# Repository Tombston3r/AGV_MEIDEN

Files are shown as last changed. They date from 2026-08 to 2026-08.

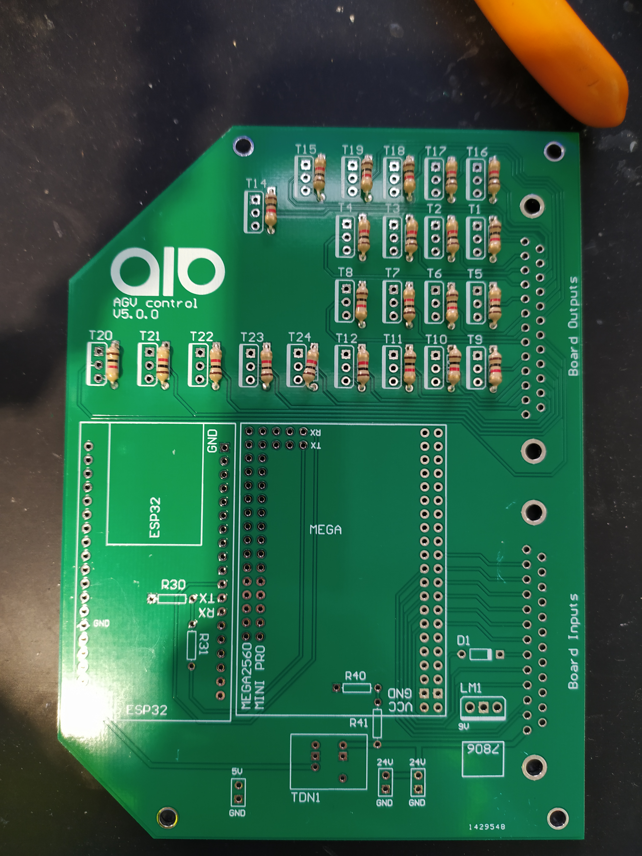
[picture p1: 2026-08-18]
Comm distance/architectures/A3_Wifi/hardware/photos/assemblagecartewifi_1.jpg

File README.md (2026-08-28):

# AGV MEIDEN

Deux chantiers sur le même chariot filoguidé MEIDEN (carte d'origine
`AIO AGV Control V5.0.1`) :

Toutes les architectures suivent la **même chaîne** depuis le 2026-08-28 :

```
Boutons d'appel (optionnels) -> Poste Central -> Carte AGV Control -> AGV
                                API planning
                                appels
```

Les boutons sont **optionnels** : le planning seul fait rouler l'AGV. Les trois
architectures ne diffèrent plus que par la **liaison du poste vers l'AGV** :
[`docs/ARCHITECTURE_COMMUNE.md`](docs/ARCHITECTURE_COMMUNE.md).

| Dossier | Chantier | État |
|---|---|---|
| [`Comm distance/`](Comm%20distance/) | **Remplacement du système d'appel** : 4 architectures étudiées (cellulaire, hybride, LoRa, Wi-Fi), bancs d'essai, matériel KiCad | 470 tests verts, choix client non tranché |
| [`Timer/`](Timer/) | **Planning journalier** : missions déclenchées sur horloge, validation quotidienne par l'opérateur | moteur livré, 18 tests verts |

Chaque chantier porte son `README.md` **et** son `DEPLOY.md`, à quoi ça sert
d'un côté, comment le mettre en service et ce qu'on doit voir de l'autre. La
règle de rangement commune est dans
[`docs/ORGANISATION.md`](docs/ORGANISATION.md) : *tout ce qui sert à une chose
vit avec elle, documentation comprise.*

Toutes les interfaces web du dépôt suivent le **même thème** : fond blanc,
bleu outremer, logo AIO : [`docs/theme/`](docs/theme/), propagé par
`outils/theme.sh`.

Les deux partagent la même carte et le même cœur métier : le Timer produira
ses missions vers le séquenceur déjà écrit dans
[`Comm distance/architectures/A3_Wifi/`](Comm%20distance/architectures/A3_Wifi/).

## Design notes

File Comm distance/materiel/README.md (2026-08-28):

# Matériel : projets KiCad

**Une carte, un projet, un seul endroit.** Même quand deux architectures
partagent une carte, elle n'est pas dupliquée : trois copies divergentes de la
V6.0 ont déjà coexisté dans ce dépôt, et il a fallu comparer les schémas pour
savoir laquelle portait le travail réel. Un firmware dupliqué se compare par
`diff` ; deux schémas KiCad divergents, non.

| Projet | Sert à | Empreintes | État |
|---|---|---:|---|
| [`AIO_AGV_Control_V5.0.1/`](AIO_AGV_Control_V5.0.1/) | **A3** : Wi-Fi | 57 | carte d'origine, **en service sur le chariot** |
| [`AIO_AGV_Control_V6.0/`](AIO_AGV_Control_V6.0/) | **A2** et **A3** : LoRa | 59 | Gerbers exportés |

## Ce qui distingue la V6.0

Le diff des deux projets ne montre **aucun écart** hors la radio : mêmes
`Mega2560 Pro` et `ESP32-DEVKITC`, mêmes 23 `IRF520` et résistances de grille,
même `L7806CV`, même `TDN 5-2411WISM`, mêmes SUB-D 25.

S'y ajoutent un **`RFM95W-868S2` (U2)** et son **embase coaxiale (J3)**.

### Brochage relevé

| RFM95W | ESP32 |
|---|---|
| `NSS` | `IO5` |
| `SCK` | `IO18` |
| `MISO` | `IO19` |
| `MOSI` | `IO23` |
| `DIO0` | `IO26` |

⚠️ **`RESET` (pad 6) n'est pas connectée.** Aucun reset logiciel n'est possible :
un module figé ne se récupérera qu'en coupant l'alimentation de la carte.
**`IO27` est libre** et conviendrait, sans fonction de strapping au démarrage,
contrairement à `IO0`, `IO2`, `IO12` ou `IO15`.

⚠️ **`IO16` et `IO17` sont réservées** : elles portent la liaison série vers le
`Mega2560 Pro`, via un pont diviseur 2,2 k / 4,7 k dans le sens 5 V → 3,3 V.

## Points relevés sur la V5.0.1, valables pour les deux

- **Les trois UART matériels du MEGA sont inutilisables** : leurs broches de
  réception portent `Y13` (D19), `Y11` (D17) et `Y05` (D15). La liaison
  inter-microcontrôleurs est en `SoftwareSerial` sur D52/D53, à 38 400 bauds.
- **L'`IRF520` n'est pas un MOSFET logic-level** : seuil spécifié de 2 à 4 V,
  `Rds(on)` garanti à Vgs = 10 V. Attaqué en 5 V il conduit, mais hors des
  conditions du constructeur. L'`IRL520N` est la version logic-level **au même
  brochage**.
- **Les 21 entrées Y arrivent directement sur les broches de l'ATmega**, sans
  protection. Le client a vérifié que les niveaux le permettent.

Le relevé complet du câblage SUB-D vit dans
[`../architectures/A3_Wifi/docs/subd25_atmega.md`](../architectures/A3_Wifi/docs/subd25_atmega.md).

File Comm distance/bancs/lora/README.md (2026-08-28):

# Banc d'essai de la liaison LoRa

Ces essais servent à répondre à une seule question avant tout déploiement :
**la liaison passe-t-elle, et les deux extrémités se comprennent-elles ?**

Ce sont deux questions distinctes, et la seconde est la plus traître. Une radio
qui porte et des trames qui divergent d'un bit donne un banc parfait et une
panne en atelier. C'est pourquoi les deux côtés utilisent **la trame
applicative du projet**, pas un message d'essai.

```
bancs/lora/
├── esp32/      carte AGV ou poste ESP32 : PlatformIO / ESP-IDF
└── linux/      poste fixe Linux : Python 3
```

Les tests unitaires du transport LoRa, eux, restent dans
[`../../architectures/A2_LoRa/test/native/`](../../architectures/A2_LoRa/test/native/) :
ils n'ont besoin d'aucun matériel et tournent avec `make test`.

## Ce qui tourne sans matériel

```bash
cd linux && ./test_interop_trame.py
```

Compile le codec C++ du cœur métier, lui fait produire des vecteurs, et vérifie
que `agv_frame.py` encode **octet pour octet la même chose** : extension
d'horodatage comprise. C'est le contrôle qui garantit que les deux dossiers
d'essai parlent vraiment la même langue.

## Les quatre combinaisons

| Émetteur | Récepteur | Ce que ça éprouve |
|---|---|---|
| `esp32/ -e tx` | `esp32/ -e rx` | La radio et le pilote du projet, en boucle |
| `linux/test_tx.py` | `linux/test_rx.py` | Le pilote Python, en boucle |
| **`esp32/ -e tx`** | **`linux/test_rx.py`** | **L'interopérabilité réelle : AGV → poste** |
| **`linux/test_tx.py`** | **`esp32/ -e rx`** | **L'interopérabilité réelle : poste → AGV** |

Les deux dernières sont celles qui comptent. Les deux premières ne prouvent que
la cohérence d'une implémentation avec elle-même.

## Côté ESP32 : deux cartes possibles

```bash
cd esp32
pio run -e v6_tx    -t upload -t monitor    # carte V6.0, émission
pio run -e v6_rx    -t upload -t monitor    # carte V6.0, écoute
pio run -e tbeam_tx -t upload -t monitor    # LILYGO T-Beam, émission
pio run -e tbeam_rx -t upload -t monitor    # LILYGO T-Beam, écoute
```

Une **LILYGO T-Beam 868 MHz** porte le **même SX1276** que le `RFM95W` de la
carte V6.0 : le `RFM95W` n'est qu'un module HopeRF enveloppant cette puce. Le
pilote du projet fonctionne donc tel quel ; seul le brochage change, et il est
décrit dans `include/test_config.h`.

### Ce qu'elle apporte au banc

**Son écran affiche le relevé en direct.** C'est ce qui rend le relevé de portée
praticable : la carte tient dans une main, on marche le long du parcours et on
lit le niveau reçu, sans ordinateur au bout d'un câble USB.

```
Banc LoRa - ecoute

RSSI    -87 dBm
SNR      +9 dB
recues 42  rej 0
marge correcte
```

Sous −115 dBm, la dernière ligne passe à `!! MARGE FAIBLE`.

**Son bouton déclenche une émission à la demande.** Au relevé, on veut mesurer
*au point où l'on se trouve*, pas au rythme d'une boucle : l'environnement
`tbeam_tx` attend un appui avant chaque trame.

**Elle est sur batterie**, et affiche sa tension : un relevé qui s'arrête est
alors une liaison perdue ou une batterie vide, et on sait laquelle.

**Sa broche `RESET` est câblée**, contrairement à la V6.0 : un module figé s'y
récupère sans couper l'alimentation.

⚠️ **Sur T-Beam, la radio est alimentée par un gestionnaire AXP192**, pas
directement. Sans l'avoir activée, le SX1276 est hors tension et `RegVersion`
lit `0x00` : on cherche alors un défaut de câblage SPI qui n'existe pas. C'est
la cause n°1 des « la radio est morte » sur cette carte. `src/tbeam_power.cpp`
s'en charge et le dit à l'écran.

⚠️ **Le brochage change d'une révision à l'autre.** Le profil fourni est celui
de la **v1.1**, la plus répandue. Sur une v0.7 (sans AXP192) ou une v1.2
(AXP2101, registres différents), vérifier avant de flasher : le numéro est
sérigraphié près du connecteur USB.

Brochage par défaut : les broches **libres** relevées au projet KiCad de la
carte V5.0.1, dont l'`ESP32-DEVKITC` n'utilise que 4 broches sur 38 :

| RFM95W | ESP32 |
|---|---|
| SCK | `IO18` |
| MISO | `IO19` |
| MOSI | `IO23` |
| NSS | `IO5` |
| RESET | `IO14` |
| DIO0 | `IO26` |

⚠️ **Ne jamais utiliser `IO16` ni `IO17`** : elles portent la liaison série
vers le `Mega2560 Pro`. Un `static_assert` le rappelle dans `test_config.h`.

Ces essais compilent le **pilote du projet** (`Sx1276Radio`) et son
**budget de rapport cyclique** (`DutyCycleBudget`), pas une bibliothèque tierce.
Ils éprouvent donc le code qui partira en production.

## Côté Linux

```bash
cd linux
sudo apt install python3-spidev python3-libgpiod
./test_tx.py --count 10 --station 42
./test_rx.py --survey                  # relevé de portée : RSSI/SNR
```

⚠️ **Un `Unipi Gate G100` ne convient pas** : c'est un boîtier DIN fermé, sans
connecteur SPI ni GPIO. Ces scripts demandent une machine qui expose un bus
SPI : un modèle UniPi à base de Raspberry Pi, ou un adaptateur USB-SPI. C'est
la raison pour laquelle la nomenclature retient une carte ESP32 pour le poste
LoRa, et non une passerelle : voir `../../architectures/A2_LoRa/BOM.md`, « Pourquoi pas un Unipi
Gate pour ce poste ? ».

## Lire les résultats

**Le taux d'accusés** est la mesure utile. 100 % sur 20 trames à poste fixe ne
prouve rien ; c'est le relevé **le long du parcours**, chariot chargé, qui
compte.

**Le RSSI plancher** décide de la marge. Sous **−115 dBm**, les deux scripts
avertissent : un chariot chargé entre les deux antennes suffira à couper la
liaison. Un lien qui « passe tout juste » ne passe pas.

**Le budget de rapport cyclique** est appliqué des deux côtés, y compris sur
les accusés : un récepteur qui acquitte est un émetteur. À SF9, une trame de
9 octets occupe ~145 ms d'antenne, ce qui plafonne à **~248 émissions par
heure**, accusés compris. Les scripts refusent d'émettre au-delà et le disent.
Ce n'est pas un réglage : c'est l'EN 300 220 / ERC 70-03.

**`--sf 7` change tout** : ~41 ms au lieu de ~145, donc 3,5 fois plus
d'émissions possibles et une latence bien plus basse, au prix de la portée.
C'est l'arbitrage décrit dans [`../../architectures/A2_LoRa/docs/latence_lora.md`](../../architectures/A2_LoRa/docs/latence_lora.md),
et ces essais sont faits pour le trancher sur le terrain plutôt qu'au bureau.

## La T-Beam peut-elle servir de télécommande finale ?

**Comme prototype, oui et c'est même recommandé.** Elle permet d'éprouver tout
le comportement du bouton A3 (protocole, latence, accusé, budget légal) et de
le faire essayer par un opérateur pendant quelques semaines, **avant** d'engager
un circuit imprimé. C'est le meilleur moyen de dérisquer la carte définitive.

**En production, non.** La raison tient en une ligne :

| | Sommeil | Réserve | Autonomie |
|---|---:|---:|---:|
| T-Beam, sommeil soigné | 0,3 mA | 18650, 3 000 mAh | **~14 mois** |
| T-Beam, sommeil courant | 1,0 mA | 18650, 3 000 mAh | **~4 mois** |
| Bouton A3 (`STM32L071` + `ER14505`) | 0,002 mA | Li-SOCl₂, 2 600 mAh | **5 à 8 ans** |

L'écart n'est pas un défaut de réglage : un ESP32 avec son gestionnaire
d'alimentation, sa puce USB-série et son écran consomme au repos mille fois ce
que consomme un microcontrôleur de la famille L0. Il ne se rattrape pas.

Trois autres points, moins spectaculaires mais réels :

- **Ce n'est pas un bouton.** C'est une carte de développement avec un accu
  18650 qui dépasse. Il faudrait lui ajouter un boîtier IP65 et un poussoir Ø22
  câblé sur une entrée, soit l'essentiel de la nomenclature du bouton A3, sans
  en avoir l'autonomie.
- **Ce n'est pas du matériel industriel** : connecteur USB exposé, pas de
  vernis, qualité grand public, dans un atelier à poussière et vibrations.
- **Les révisions changent de brochage** et sortent du catalogue. Pour une
  installation prévue pour dix ans, c'est un risque d'approvisionnement.

En revanche, **rien ne s'oppose à ce qu'elle serve de poste fixe d'essai** dans
l'architecture A2 : sur secteur, la consommation n'a plus d'importance, et son
écran affiche l'état de la liaison.

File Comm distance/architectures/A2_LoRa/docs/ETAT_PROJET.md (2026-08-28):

# État du projet : architecture Wi-Fi (carte V5.0.1 conservée)

> **Document vivant.** Mis à jour à chaque modification du dossier.
>
> Dernière mise à jour : **2026-08-18**, poste fixe ramené à une passerelle
> Unipi Gate G100, ce qui lève le point ouvert §12.9.
>
> **Périmètre** : `architectures/A3_Wifi/`, projet autonome et zippable. La carte AIO
> AGV Control V5.0.1 est **conservée** ; ses **deux firmwares sont réécrits**.
> Index des architectures : [`../../README.md`](../../README.md).
> Spécification suivie : [`Planification_Architecture_WiFi_AGV.md`](Planification_Architecture_WiFi_AGV.md).

---

## 1. Ce qui est fait

### 1.1 Vue d'ensemble

| Indicateur | Valeur |
|---|---|
| Tests natifs C++ | **109 tests, 537 assertions, 0 échec** |
| Tests Python (poste UniPi) | **17 tests, 0 échec** (rejoués à la main, `pytest` absent du poste) |
| Compilation | `-std=c++17 -Wall -Wextra -Werror`, sans avertissement |
| Matériel nécessaire | **aucun** |
| Firmwares réécrits | ESP32 **et** ATmega2560 |

```bash
python3 tools/genconfig.py profiles/default.yaml \
        firmware/common/config/generated_profile.h
make test
```

### 1.2 Répartition des rôles : la décision structurante

Détail et justification : [`carte_v5_architecture.md`](carte_v5_architecture.md).

| Microcontrôleur | Porte | Ne porte pas |
|---|---|---|
| **ATmega2560** | séquenceur trois phases, file de 5 courses, décodage position 10 bits, repli de sécurité | rien de réseau |
| **ESP32** | client Wi-Fi STA, client MQTT, heartbeat, AP de maintenance, `/agvdump` | **jamais le bus MEIDEN** |

Motif : chaque maillon réseau (Wi-Fi, DHCP, handover, TLS, broker, poste) peut
tomber pour des raisons hors projet. Le séquenceur ne doit dépendre d'aucun.

### 1.3 Repli de sécurité : le mécanisme central

L'ESP32 émet un heartbeat toutes les 500 ms. Sans heartbeat pendant 2 s,
l'ATmega termine la course engagée **jusqu'au point d'arrêt suivant**, refuse
toute nouvelle course, et le signale (`safe_stop`).

Vérifié par 6 tests dédiés, dont :

- refus de toute course tant qu'aucun heartbeat n'a été reçu (état au boot) ;
- perte en pleine course → la course va au bout, la suivante n'est pas lancée ;
- **le retour du heartbeat ne relance rien tout seul** ;
- un heartbeat manqué isolément n'immobilise pas l'AGV.

### 1.4 Firmware ATmega2560 (réécrit)

| Élément | État |
|---|---|
| Séquenceur trois phases, 12 états, tous timeouts instrumentés | ✅ |
| File de 5 courses, priorité, purge | ✅ (RAM, planification §2.3) |
| Décodage position 10 bits `Y23`…`Y34` et vitesse `Y11`…`Y14` | ✅ |
| Pose des 22 lignes en **une seule section critique** (5 écritures de port) | ✅ testé |
| Masquage des ports mixtes PA/PB/PG (DDR et données) | ✅ testé |
| Étage de sortie **poussé** : la broche attaque une grille de MOSFET | ✅ testé |
| Table de câblage réelle CN61→CN64 | ✅ relevée |
| Idempotence : même séquence ré-acquittée sans ré-exécution | ✅ |
| Repli heartbeat | ✅ |
| **Mode découverte du brochage SUB-D** | ✅ (contrôle, plus relevé) |

### 1.5 Firmware ESP32 (réécrit)

| Élément | État |
|---|---|
| Client Wi-Fi **STA** (plus de point d'accès permanent) | ✅ |
| IP statique pour supprimer le délai DHCP au handover | ✅ |
| Client MQTT : `state` (retained, 1 s), `cmd`, `ack`, LWT sur `status` | ✅ |
| Heartbeat vers l'ATmega, **maintenu même sans Wi-Fi** | ✅ testé |
| Péremption des commandes (30 s), doublons, désordre | ✅ testé |
| AP de maintenance à la demande (ILS, 10 min) en **APSTA** | ✅ |
| `/agvdump` au format atelier | ✅ testé |

### 1.6 Liaison inter-MCU

Protocole documenté dans `link/link_protocol.h` : SOF distinct par sens,
CRC-16/CCITT, resynchronisation automatique, longueur invalide rejetée.
7 tests dédiés.

### 1.7 Poste fixe UniPi

| Élément | État |
|---|---|
| Décodeur ESP3 (TCM 515) en Python | ✅ |
| Déduplication des 3 sous-télégrammes PTM 210 | ✅ |
| Table d'appairage persistée + mode appairage | ✅ |
| Publication MQTT horodatée, séquence roulante | ✅ |
| Traçabilité des appuis (`poste/1/button/<id>`) | ✅ |
| Indicateur de fraîcheur de l'état | ✅ |
| Service systemd | ✅ |

### 1.8 Ce qui n'a **pas** pu être vérifié ici

- **Aucun des deux firmwares n'a été compilé pour sa cible** : ni PlatformIO,
  ni ESP-IDF, ni avr-gcc sur ce poste. Le cœur métier compile en natif avec
  `-Werror`, ce qui couvre la logique, pas les API ESP-IDF/Arduino.
- **`pytest` absent** : les 17 tests Python ont été rejoués par un harnais
  maison, pas par pytest.
- **Aucun essai matériel** : ni carte, ni banc, ni AGV, ni relevé réseau.
- **L'amplitude des lignes Y reste inconnue** (W1b), et la nomenclature KiCad
  confirme qu'**aucune protection n'est prévue** : la carte ne compte que quatre
  résistances hors étage de sortie, deux diviseurs de mesure. Les 21 lignes `Y`
  arrivent directement sur les broches du Mega. C'est la mesure la plus urgente.
- **La tension V_CC réelle de l'ATmega n'est pas mesurée** (W1e) : 6 V est le
  maximum absolu du datasheet.

---

## 2. Déploiement en conditions réelles

> 📖 **Procédure opérationnelle détaillée : [`../DEPLOY.md`](../DEPLOY.md)**,
> checklists, commandes, essais de recette et fiche à viser. Ce qui suit en est
> le résumé ; en cas d'écart, c'est `DEPLOY.md` qui fait foi.
>
> ⚠️ **Ordre non négociable.** Les étapes 0 à 2 conditionnent tout le reste.

### Étape 0 : Prérequis bloquants (planification §3)

| # | Tâche | Pourquoi bloquant |
|---|---|---|
| 0.1 | **Accord du service informatique** : VLAN OT, IP, pare-feu, 802.1X, notification de changement | Chemin critique du projet, délai hors de votre contrôle. À lancer le jour 1 |
| 0.2 | **Relevé de couverture Wi-Fi à hauteur d'antenne AGV**, trajet complet, en production | Un relevé fait à 1,50 m avec un portable ne vaut rien |
| 0.3 | Test de portée EnOcean bouton → poste, à chaque marqueur | Un bouton hors portée échoue **silencieusement** |
| 0.4a | ⚠️ **Mesurer l'amplitude d'une ligne Y** (`Y05`) et la tension V_CC de l'ATmega | Les Y arrivent directement sur des broches ; au-delà de V_CC + 0,5 V l'entrée est détruite. **Avant tout branchement** |
| 0.4c | Mesurer le tirage des entrées de l'automate | Décide entre collecteur ouvert et sortie poussée |
| 0.4b | Chronogramme X/Y, `t_setup`, PNP/NPN | Sans ça, les timings du profil sont des devinettes |
| 0.5 | Tentative de lecture des flash existantes (`esptool`, `avrdude`/ICSP) | Peut confirmer ou infirmer les hypothèses de câblage |
| 0.7 | **Décision de bande** : 2,4 GHz, ESP32-C5 bi-bande, ou bridge industriel | La saturation 2,4 GHz est le problème d'origine |

### Étape 1 : Poste de développement

```bash
pip install platformio
cd poste-unipi && pip install -e '.[dev,mqtt,enocean_serial]' && cd ..

python3 tools/genconfig.py profiles/default.yaml \
        firmware/common/config/generated_profile.h
make test
cd poste-unipi && python3 -m pytest tests -q && cd ..
```

### Étape 2 : Contrôle du brochage SUB-D, automate débranché

La table est **relevée** ([`subd25_atmega.md`](subd25_atmega.md)) ; il reste à
vérifier qu'aucune nappe n'est sertie à l'envers. Une erreur de sertissage
n'échoue pas : elle envoie l'AGV à la mauvaise station.

```bash
pio run -e mega -t upload        # via l'ICSP ou le bootloader, selon la carte
pio device monitor -b 115200     # puis envoyer 'd'
```

Reporter le relevé dans `board_ports.h` et `profiles/default.yaml`, régénérer,
relancer `make test`.

### Étape 3 : Renseigner le profil

Éditer `profiles/default.yaml` **et rien d'autre** : timings relevés (§12.4,
§12.5), polarité (§12.3), paramètres réseau (W5) et MQTT (W6).

### Étape 4 : Infrastructure (planification §4)

1. VLAN, adressage, pare-feu côté client.
2. Mosquitto sur l'UniPi : TLS, authentification par utilisateur, **ACL par
   topic** : l'AGV ne doit pouvoir publier que sur `agv/1/#`.
3. Validation du positionnement des AP si le relevé 0.2 montre des trous.
4. Mesure du temps de reconnexion au handover, IP statique activée.

### Étape 5 : Flash des deux firmwares

```bash
pio run -e mega  -t upload       # ATmega2560 : séquenceur + file
pio run -e esp32 -t upload       # ESP32 : Wi-Fi + MQTT + heartbeat
```

⚠️ Flasher l'ATmega **en premier** : au démarrage il est en `safe_stop` et
refuse toute course tant que l'ESP32 ne bat pas. L'ordre inverse laisse un ESP32
qui parle dans le vide.

### Étape 6 : Poste fixe UniPi

```bash
sudo useradd -r -s /usr/sbin/nologin agv
sudo mkdir -p /opt/agv /etc/agv /var/lib/agv
sudo python3.11 -m venv /opt/agv/venv
sudo /opt/agv/venv/bin/pip install './poste-unipi[mqtt,enocean_serial]'
sudo cp poste-unipi/poste.example.toml /etc/agv/poste.toml
sudo $EDITOR /etc/agv/poste.toml       # port TCM 515, broker, identifiants
sudo cp poste-unipi/systemd/agv-poste.service /etc/systemd/system/
sudo systemctl enable --now agv-poste
journalctl -u agv-poste -f
```

### Étape 7 : Mise en service

1. Appairer chaque bouton EnOcean depuis l'IHM, puis **vérifier chaque bouton
   depuis son emplacement définitif** (la portée se teste là où le bouton sera
   posé, pas sur l'établi).
2. Vérifier `/agvdump` : approcher l'aimant du contact ILS, 10 minutes.
3. Essais de dégradation, dans cet ordre : coupure AP, redémarrage UniPi,
   **débranchement de la liaison série ESP32↔ATmega en pleine course**, bouton
   hors portée.
4. Campagne en heures de production : latence P50/P95/P99, taux de perte,
   handovers (planification §7.4).

### Diagnostic sur site

| Symptôme | Où regarder |
|---|---|
| L'AGV refuse toutes les courses | `safe_stop` dans `/agvdump` ou MQTT → heartbeat perdu, donc ESP32 ou liaison série |
| L'AGV ne part pas mais accepte | `write_op_return`, `start_op_return`, `fault` |
| Appels perdus par moments | `rssi_dbm`, relevé 0.2 insuffisant, handover |
| Commandes ignorées | `cmd_expired` → horloge du poste ou latence réseau |
| Courses en double | `cmd_duplicate`, si nul, l'idempotence ne voit pas les rejeux |
| Appuis sans effet | `unpaired` côté poste → bouton non appairé, ou hors portée |
| État figé dans l'IHM | indicateur de fraîcheur : LWT `offline` sur `agv/1/status` |

---

## 3. Kanban

### 🔴 Bloqué : relevé ou décision client

| # | Tâche | Débloqué par |
|---|---|---|
| LG2 | Câbler une GPIO vers `RESET` du RFM95W sur une révision V6.1 | Relevé V6.0 : la broche n'est pas connectée |
| B1 | Renseigner `t_setup_us` et les timeouts `Y22`/`Y05`/`Y10` | Relevé à l'analyseur logique (0.4, §12.4-12.5) |
| ~~B2~~ | ~~Qualifier l'amplitude des lignes Y~~ | ✅ **vérifié par le client le 2026-08-21** |
| B2c | Confirmer la topologie de l'étage de sortie (`x_open_drain`) | Mesure du tirage côté automate (W1d) |
| B2d | Vérifier la tension V_CC de l'ATmega | 6 V = maximum absolu du datasheet (W1e) |
| B2b | Trancher les pull-ups internes sur les Y | Sorties automate à collecteur ouvert ou poussées ? (W1c) |
| B3 | Figer la polarité PNP/NPN | Mesure sur l'automate (§12.3) |
| B4 | Recaler le format `/agvdump` | Sortie réelle de la V5.0.1 (§12.6, §3.3) |
| B5 | Paramètres réseau et MQTT | Accord du service informatique (0.1, W5, W6) |
| ~~B6~~ | ~~Confirmer l'UART ESP32 ↔ ATmega~~ | ✅ **relevé au KiCad** : SoftwareSerial D52/D53, 38 400 bd |
| B6b | Vérifier au banc la tenue de `SoftwareSerial` à 38 400 bauds sous charge du séquenceur | L'émission logicielle masque les interruptions pendant chaque octet |
| B7 | Décider de la bande 2,4 GHz vs bi-bande | Arbitrage 0.7 |
| B2e | ⚠️ **Trancher l'étage de sortie** : `IRF520` (hors spec à 5 V), `IRL520` (logic-level, même brochage) ou `ULN2803A` | Le PCB est-il déjà fabriqué ? (analyse `BOM.md`) |
| B2f | Décider si l'isolation galvanique est requise : le `TDN 5-2411WISM` isolé cohabite avec des MOSFET à masse commune | Arbitrage client ; ~22 € en jeu (analyse `BOM.md`) |
| ~~B8~~ | ~~Runtime de l'UniPi~~ | **LEVÉ** si le Gate G100 est retenu : livré sous Debian |
| B9 | Voyant d'accusé opérateur | Décision client (planification §3.6) |

### 🟡 À faire, sans dépendance externe

| # | Tâche | Effort |
|---|---|---|
| T1 | **Compiler les deux firmwares** (`pio run -e esp32`, `-e mega`) et corriger les erreurs d'API | M |
| T2 | Vérifier l'empreinte RAM/flash de l'ATmega (8 Ko de SRAM) | S |
| T3 | Exécuter les tests Python sous 3.11 avec `pytest`, `ruff`, `mypy --strict` | S |
| T4 | Interface web de supervision servie par le poste (WebSocket) | M |
| T5 | Journal d'événements côté poste (planification §3.5) | M |
| T6 | Intégration continue (`make test` + build PlatformIO + lint Python) | S |
| T7 | Persistance EEPROM de la file sur l'ATmega, en option | S |
| T8 | Surveiller une ligne de heartbeat matérielle si le relevé en révèle une | S |
| T9 | Banc HIL : firmware du simulateur d'automate sur les 43 lignes | L |
| T10 | Durcissement Mosquitto : ACL par topic, rotation des certificats | S |

### 🔵 Backlog

| # | Tâche |
|---|---|
| S1 | Mise à jour OTA de l'ESP32 pendant la fenêtre de maintenance |
| S2 | Reflash de l'ATmega depuis l'ESP32 (l'ESP32 en programmateur ISP) |
| S3 | Historique long terme et export CSV côté poste |
| S4 | Repli automatique sur une bande ISM si le Wi-Fi est durablement perdu |

### ✅ Fait

| Livrable | Détail |
|---|---|
| Firmware ATmega2560 réécrit | Séquenceur, file, repli heartbeat, mode découverte |
| Firmware ESP32 réécrit | Wi-Fi STA, MQTT, heartbeat, AP de maintenance, agvdump |
| Protocole inter-MCU | CRC-16, SOF par sens, resynchronisation |
| JSON MQTT | Sérialiseur et analyseur minimaux, testés |
| Driver de bus AVR | Pose des 22 lignes en une section critique |
| Mode découverte du brochage | Une ligne à la fois, pour le relevé au multimètre |
| Poste fixe UniPi | ESP3, déduplication, appairage, MQTT, fraîcheur |
| Simulateur d'automate | Repris du cœur commun |
| 101 tests C++ + 17 tests Python | Dont 6 sur le repli heartbeat |
| Documentation | Architecture de la carte, brochage SUB-D, essais, questions |
| Matériel | Projet KiCad de la carte V5.0.1 et photo d'assemblage dans `hardware/` |
| **Nomenclature chiffrée** | `BOM.md` : matériel, outillage, récurrent, coût sur 10 ans |
| **Runbook de déploiement** | `DEPLOY.md` : 11 phases, checklists, recette, retour arrière |

---

## 4. Journal des mises à jour

| Date | Modification | Impact |
|---|---|---|
| 2026-08-28 | **Fusion des deux variantes LoRa et boutons rendus optionnels.** Elles ne se distinguaient que par la technologie du bouton : les boutons étant devenus optionnels, cette distinction ne définissait plus une architecture. `A2_Hybride` et `A3_LoRa` deviennent **`A2_LoRa`**, l'ancienne `A4_Wifi` devient **`A3_Wifi`** pour garder une numérotation continue. **Les boutons sortent des nomenclatures** : le planning seul fait rouler l'AGV, et leur choix reste ouvert, indépendant de l'architecture. Disparaissent avec eux le point de bascule entre variantes et les tableaux « coût par station », qui ne mesuraient que des boutons. Le poste ESP32 de l'ancienne A2 est supprimé (le poste est Linux), ainsi que le décodeur ESP3 en C++ de ce dossier, celui du poste étant en Python dans le banc. **Le banc EnOcean est conservé** : il validera les `PTM 210` si l'option est retenue. Trois architectures, un seul critère de choix : la liaison du poste vers l'AGV. A2 = 417 €, A3 = 592 €, A1 = 426 € plus 96 €/an. | arborescence, BOM, comparatif |
| 2026-08-28 | **Modèle d'architecture commun** : boutons d'appel optionnels, **poste central** hébergeant l'API de planning et recevant les appels, carte AGV Control, AGV. Les quatre architectures ne diffèrent plus que par la technologie de chaque liaison ([`ARCHITECTURE_COMMUNE.md`](../../../../docs/ARCHITECTURE_COMMUNE.md)). Trois conséquences. **A3 gagne un poste** (UniPi Lite 1.1, +209 € HT) et **perd son argument principal**, l'absence d'infrastructure ; elle conserve le bouton authentifié et l'accusé visuel. **Les postes ESP32 de A1 et A2 passent sous Linux** : héberger une API web, un planning persistant et un journal sur un microcontrôleur coûte trop en logiciel. **Le Timer quitte la carte AGV** pour le poste, ce qui fait disparaître le DS3231, la contrainte NVS et le serveur web à rendre permanent. Les quatre solutions se tiennent désormais entre **525 et 700 € HT** : le coût cesse d'être discriminant. ⚠️ **A2 et A3 ne sont plus séparées que par 19 € et le type de bouton** : question ouverte au client dans `COMPARAISON.md`. | les 4 architectures, BOM, comparatif |
| 2026-08-27 | **Tirets cadratins retirés de tout le dépôt** sur demande du client : 2318 occurrences, 360 fichiers, documentation, commentaires de code, chaînes affichées et gabarits web. Remplacement **contextuel** plutôt qu'uniforme : deux-points quand la suite explique, virgule après une liaison (*et, mais, donc, dont, notamment*), parenthèses pour une incise complète, trait d'union simple pour une valeur absente dans un tableau. Deux défauts corrigés au passage : le générateur produisait « Nomenclature : A3 : LoRa » (double ponctuation, le titre portant déjà son code), et le libellé de plage « Numérotation A1-A3 » avait vu sa borne basse renumérotée par mes permutations successives A1/A2 puis A2/A3. Contrôles passés : fidélité `agvdump`, conformité du thème, 470 + 53 + 19 tests. | tout le dépôt |
| 2026-08-27 | **Thème unifié sur toutes les interfaces du dépôt**, fond blanc, texte noir, bleu outremer, logo AIO : les six IHM (4 supervisions d'architecture, banc EnOcean, planning) partageaient jusqu'ici **trois palettes différentes**, deux sombres et une claire. La feuille vit une seule fois dans `docs/theme/theme.css` ; chaque interface en porte une copie (dossiers livrables seuls, et le banc part en `rsync` sur une UniPi). `outils/theme.sh` propage l'original et **signale les copies qui ont dérivé**, même garde que pour le rendu `agvdump`. Les `style.css` ne gardent que le spécifique. Deux défauts trouvés au rendu : le serveur du banc planning servait **tout** en `text/html`, donc la feuille était ignorée ; et les notifications recouvraient l'en-tête. Le banc EnOcean passe en **v1.2.0** pour que le contrôle de version du déploiement signale une copie périmée. | 6 interfaces, thème, outils |
| 2026-08-26 | **Banc LoRa : l'écran et le bouton de la T-Beam sont exploités.** Le profil de carte ne suffisait pas, sans écran, le relevé de portée exige encore de promener un ordinateur au bout d'un câble USB. `oled.{h,cpp}` est un pilote SSD1306 minimal (texte seul, aucune dépendance tierce) qui affiche RSSI, SNR, compteurs et tension batterie ; sous −115 dBm il annonce `!! MARGE FAIBLE`. Le bouton de la carte déclenche **une** émission à la demande, pour mesurer au point où l'on se trouve plutôt qu'au rythme d'une boucle. La police 5×7 est **vérifiée par rendu** (`test_hote/rendu_police.cpp`) : un `static_assert` et le rendu ASCII ont pris un antislash en fin de commentaire qui avalait le glyphe suivant, 94 glyphes au lieu de 95. Avec deux T-Beam, le relevé se fait à deux personnes, sans matériel informatique. | banc LoRa |
| 2026-08-26 | **Banc LoRa : prise en charge de la LILYGO T-Beam 868 MHz.** Elle porte le **même SX1276** que le `RFM95W` de la V6.0 (le `RFM95W` n'est qu'un module HopeRF enveloppant cette puce) donc le pilote du projet fonctionne tel quel. `test_config.h` devient un profil de carte choisi par drapeau (`CARTE_V6` / `CARTE_TBEAM`), quatre environnements PlatformIO. ⚠️ **Sur T-Beam la radio est alimentée par un AXP192**, pas directement : sans activation de LDO2 le SX1276 est hors tension et `RegVersion` lit `0x00`, ce qui fait chercher un défaut de câblage SPI inexistant. `src/tbeam_power.cpp` s'en charge, coupe le GPS et remonte un diagnostic lisible selon la révision (v0.7 sans PMU, v1.2 en AXP2101). Deux avantages au banc : batterie intégrée pour le relevé de portée sans ordinateur, et broche `RESET` câblée contrairement à la V6.0. **Verdict pour la télécommande finale : non en production** (4 à 14 mois d'autonomie sur 18650 contre 5 à 8 ans pour le bouton A3 sur `ER14505`) **mais oui comme prototype**, pour éprouver le protocole avant d'engager un PCB. | banc LoRa |
| 2026-08-26 | **Réorganisation du dépôt par NATURE d'objet.** `architectures/` (les 4 solutions), `bancs/` (les essais matériels), `materiel/` (les projets KiCad), `docs/` (brief et comparatif), `outils/` (scripts). Le dossier `CarteComm/` disparaît. **Le matériel n'est plus dupliqué** : une carte, un projet, un seul endroit, trois copies divergentes de la V6.0 avaient déjà coexisté, dont une que KiCad avait recréée à un chemin renommé, et il a fallu comparer les schémas pour trouver la vivante (celle du 26 août, avec l'embase J3 et les Gerbers). Le **brief** passe de 4 copies à 1. Les **bancs LoRa sortent de `A2_LoRa/test/`** pour rejoindre `bancs/lora/`, à la même forme que le banc EnOcean ; `test/native/` ne garde que les tests unitaires. Chaque banc a désormais son `README.md` **et** son `DEPLOY.md` avec une recette et les résultats attendus. `outils/exporter_architecture.sh` reconstitue une architecture autonome dans un zip, la zippabilité est payée à l'export, plus tous les jours. Le générateur de nomenclatures n'a plus de chemin absolu. **2 Mo de redondance supprimés.** | arborescence, tous les renvois |
| 2026-08-25 | **La passerelle MQTT est remplacée par une passerelle LoRa.** `GatewayApp` publiait sur des topics et dépendait d'`IMqttPublisher` : il n'avait rien à faire dans une architecture sans broker. `LoraGatewayApp` le remplace, trames applicatives de 9 octets sur `ITransport`, accusé par la même voie, idempotence `(node_id, seq)` en table locale, et le **budget de rapport cyclique appliqué aux accusés** puisqu'un récepteur qui acquitte est un émetteur. Le firmware ESP32 est réécrit : plus de Wi-Fi STA ni de client MQTT, mais SPI + `Sx1276Radio` + `LoraTransport`, avec le brochage relevé au KiCad dans `board_pins.h`. `MqttConfig` et `WifiConfig` quittent le profil, la section `lora:` y entre, `aes_enabled` passe à **true**, sans TLS, le chiffrement applicatif est la seule protection de la liaison. Le champ `mqtt_up` d'`/agvdump` est **conservé** : c'est un contrat d'atelier (§3.3), il porte désormais l'état radio. **Kanban LG1 soldé.** | firmware, profils, tests |
| 2026-08-25 | ⚠️ **Deux défauts trouvés en écrivant les tests.** (1) La détection de silence de l'ATmega utilisait `0` comme sentinelle « jamais reçu », alors que c'est un instant valide au démarrage : elle était inopérante pendant les premières millisecondes. Corrigé par un drapeau explicite. (2) Le `Makefile` ne suivait **pas les dépendances d'en-têtes** : modifier une classe ne recompilait pas ses utilisateurs, et l'on reliait des objets compilés contre deux versions de la même classe, un test échouait sans qu'aucune erreur ne soit signalée. `-MMD -MP` ajouté aux **quatre** Makefile. | firmware, Makefile |
| 2026-08-25 | **La carte LoRa est la `AIO_AGV_Control_V6.0`, et elle est FABRIQUÉE.** Le diff des deux projets KiCad est sans ambiguïté : 58 empreintes contre 57, **un seul écart, le `RFM95W-868S2`**, tout le reste est identique au composant près. La radio est intégrée, câblée sur le SPI libre de l'ESP32 : ni carte fille, ni câblage volant. Les nomenclatures chiffraient jusqu'ici une V5.0.1 **réutilisée à 0 €** augmentée d'une carte fille à 18 € ; c'était une hypothèse de travail, remplacée par la nomenclature réelle à **111,15 € HT**. Conséquence assumée : **A3 passe de 208 à 329 €** et **A2 de 307 à 428 €** accessoires compris. Trois analyses devenues fausses sont réécrites, « réutiliser la carte existante », la question des optocoupleurs (la V6.0 a des MOSFET, pas de `PC847`) et le choix `shift595`. La table d'équivalences, jusqu'ici partagée, devient propre à chaque architecture : elle listait des composants absents de la carte concernée. | BOM, README, COMPARAISON |
| 2026-08-25 | **A2 et A3 permutés** : l'hybride EnOcean + LoRa devient **A2**, le LoRa pur devient **A3**, l'hybride a été étudié avant. Les dossiers suivent : `A3_Hybride/` → `A2_LoRa/` et `A2_LoRa/` → `A2_LoRa/`, ainsi que les documents de référence. Chaque dossier ne garde désormais **que sa propre spécification** : la copie étrangère héritée de la duplication est retirée. Le brief et l'index racine sont réordonnés pour se lire A1, A2, A3, A3. **Les variables du générateur cessent d'encoder un numéro d'architecture**, `bouton_a1` devient `bouton_pile`, `poste_a3` devient `poste_enocean`, `a1_ht` devient `ht_lora_pur` : c'est ce qui faisait revenir ce travail à chaque permutation. `subd25_atmega.md` reste exclu, `A2`/`A3` y désignant des broches de connecteur. | arborescence, BOM, brief, README |
| 2026-08-25 | **Réorganisation : un dossier par ARCHITECTURE et non plus par mode de communication.** `SMS_EnOcean/` → `A1_Cellulaire/`, `Wifi/` → `A3_Wifi/`, `LoRa/` → `A2_LoRa/`, et **`A2_LoRa/` est créé**. A3 et A2 étaient jusqu'ici un dossier de sources non autonome : ils reçoivent le cœur métier de A3 (c'est lui qui porte le duo MEGA + ESP32 de la carte V6.0, pas le firmware mono-ESP32 de A1) plus le transport LoRa, et A2 y ajoute le décodage ESP3 et le poste fixe. **Les quatre dossiers compilent et testent seuls** : 112, 119, 130 et 109 tests. Côté matériel, `AIO_AGV_Control_V6.0` quitte A3 pour A3 et A2 : le relevé KiCad montre que c'est la V5.0.1 **plus un `RFM95W-868S2`** (58 empreintes contre 57), câblé `NSS`→`IO5`, `SCK`→`IO18`, `MISO`→`IO19`, `MOSI`→`IO23`, `DIO0`→`IO26`, exactement le brochage supposé. ⚠️ **`RESET` n'est pas câblée**, `kPinReset` passe à `0xFF` et une carte de kanban est ouverte. ⚠️ Dette assumée : le firmware ESP32 de A3 et A2 porte encore la passerelle MQTT héritée de A3, à remplacer par un `LoraGatewayApp` (kanban LG1). | arborescence, BOM, README, journaux |
| 2026-08-25 | **A1 et A3 permutés** : le cellulaire devient **A1**, le LoRa homogène devient **A3**, la numérotation suit désormais l'ordre chronologique d'étude, le SMS ayant précédé le LoRa. A2 (hybride) et A3 (Wi-Fi) sont inchangés. Permutation appliquée à 10 fichiers, dont **le brief**, dont la table des architectures est aussi réordonnée ; les deux copies restent identiques. Les documents de référence sont renommés (`Archi_1_Cellulaire_SMS_LTE-M.md` et `Archi_2a_LoRa_P2P_homogene.md`) et leurs six renvois suivis. **Deux faux positifs protégés** : le repère KiCad `Mega2560 Pro (A1)`, et l'intégralité de `subd25_atmega.md`, où `A1`/`A3` désignent des broches de connecteur et non des architectures. | brief, BOM, README, COMPARAISON, DEPLOY |
| 2026-08-25 | **Numérotation A1–A3 rendue explicite dans les nomenclatures.** Le retrait des accessoires couvrait déjà les quatre architectures (42 lignes), mais seules A3 et A2 portaient leur code : les titres, les sections et les blocs Total nomment désormais **A1** (cellulaire) et **A3** (Wi-Fi) au même titre. `README.md` gagne une colonne `Code` et `COMPARAISON.md` complète ses libellés. `tools/prix_a_completer.md` est aligné : 7 lignes d'accessoires retirées, section « Boîtiers » supprimée, section 2 renommée « Radio », et une **enveloppe de sourcing** (~1 630 € HT) ajoutée, explicitement présentée comme une borne d'effort de recherche et **non un budget**, puisqu'elle additionne des alternatives qui s'excluent. | BOM, README, COMPARAISON, feuille de sourcing |
| 2026-08-25 | **Nomenclatures resserrées sur les composants déterminants.** Les accessoires arbitrables selon le budget (antennes, boîtiers, coffrets, enveloppes murales, câbles, plaques gravées) sont retirés de l'affichage et des sous-totaux : 36 lignes, qui se substituent librement d'un fournisseur à l'autre et n'engagent aucun choix de conception. Chaque `BOM.md` s'ouvre désormais sur un **bloc Total** rappelant, par variante, le montant des accessoires écartés, sans quoi un total amputé se lirait comme un coût d'achat complet. Les définitions restent dans `tools/generer_bom.py`, marquées `core=False`. ⚠️ `README.md` et `COMPARAISON.md` continuent de raisonner **accessoires compris** : comparer des architectures sans leurs boîtiers fausserait le classement. Le point de bascule A3/A2 est d'ailleurs devenu **calculé** au lieu d'être asséné, il passe de 8 à 9 stations, et deux coûts par station encore codés en dur ont été branchés sur les sections. | BOM, README, COMPARAISON |
| 2026-08-22 | **Essais radio LoRa** ajoutés dans `../../A2_LoRa/test/`, en deux sous-dossiers `esp32/` et `unipi/`, chacun avec un essai d'émission et un de réception. Les quatre combinaisons sont possibles ; les deux croisées sont celles qui comptent, car elles seules éprouvent l'interopérabilité. Les deux côtés parlent la **trame applicative du projet**, et `test_interop_trame.py` (le seul essai qui tourne sans matériel) compile le codec C++ du cœur pour vérifier que le portage Python encode **octet pour octet la même chose** : 6 vecteurs, extension d'horodatage comprise, 0 écart. Le budget de rapport cyclique est appliqué des deux côtés, accusés compris. | `LoRa/test/`, journal |
| 2026-08-21 | ⚠️ **Correction de firmware, la liaison inter-MCU n'est pas un UART matériel.** Le relevé du projet KiCad montre `ESP32 IO17` → `MEGA D52` en direct, et `MEGA D53` → pont 2,2 k/4,7 k → `ESP32 IO16`. Or D52/D53 ne sont pas des broches d'UART sur le MEGA, et **ses trois UART sont inutilisables** : leurs broches de réception portent `Y13` (D19/PD2), `Y11` (D17/PH0) et `Y05` (D15/PJ0). Le `Serial1.begin()` que contenait `firmware/mega/src/main.cpp` aurait mis **Y13 en sortie contre la sortie de l'automate**. Passage en `SoftwareSerial` sur D52/D53 et **abaissement à 38 400 bauds**, 115 200 n'étant pas tenable en émulation logicielle sur AVR. **W2 est clos.** | §1.6, W2, `profiles/default.yaml`, 109 tests toujours verts |
| 2026-08-21 | **W1b clos** : le client a vérifié l'amplitude des lignes Y, la connexion directe sur broches d'ATmega est confirmée compatible. La valeur mesurée reste à consigner dans `questions_ouvertes.md` pour la traçabilité. | W1b, kanban B2 |
| 2026-08-21 | Troisième variante d'interface bus chiffrée pour l'architecture LoRa : **`avr_port`**, alignée sur la topologie de la V5.0.1. Un `Mega2560 Pro` porte les 43 lignes sur ses broches, les 11 `PC847` disparaissent, et `avr_port_bus.cpp` (écrit et testé ici) se réutilise avec son relevé de câblage. 12 € HT de plus, une conception matérielle au lieu de deux. **Contrepartie : W1b devient strictement bloquant**, un optocoupleur encaisse 24 V, une broche d'ATmega non. La V5.0.1 relie pourtant ses 21 entrées Y directement depuis cinq ans, ce qui rend l'hypothèse « lignes en logique » très probable sans la démontrer. | BOM LoRa, W1b |
| 2026-08-21 | Colonne **`Lien d'achat`** ajoutée aux nomenclatures et à `tools/prix_a_completer.md`, en remplacement de la colonne `Source` qu'elle rend redondante. **RS est mis en tête partout**, y compris sur les références EnOcean et Unipi qu'il ne distribue habituellement pas : le catalogue évolue et une commande groupée chez un fournisseur référencé vaut souvent le surcoût unitaire. Ce sont des liens de **recherche sur la référence fabricant**, pas des fiches produit, le site de RS bloque l'accès automatisé, aucun numéro de stock n'a donc pu être vérifié. Des numéros inventés auraient produit des liens crédibles menant à la mauvaise pièce. | BOM, feuille de sourcing |
| 2026-08-20 | **Analyse critique de la carte routée** ajoutée à `BOM.md`. Trois points relevés sur le projet KiCad. (1) L'`IRF520` n'est **pas** un MOSFET logic-level : seuil spécifié de 2 à 4 V, `Rds(on)` garanti à Vgs = 10 V. Il conduit sous 5 V et convient aux quelques milliampères d'une entrée d'automate, mais hors conditions constructeur ; l'`IRL520` est une substitution sans reroutage, l'`ULN2803A` divise la surface par dix. (2) Le convertisseur **isolé** `TDN 5-2411WISM` (poste le plus cher de la carte) cohabite avec un étage de sortie à **masse commune** : l'isolation ne protège pas les signaux, et si elle ne visait qu'eux, un `TSR 1-2450` économise ~22 €. (3) Le 6 V du `L7806CV` reste au maximum absolu de l'ATmega alors qu'un 5 V propre existe déjà sur la carte. Aucun changement de nomenclature : ces trois points sont des **décisions**, pas des corrections. | §3 kanban B2e/B2f, BOM |
| 2026-08-18 | Poste fixe : l'automate UniPi est remplacé par une passerelle **Unipi Gate G100** (~200 € au lieu de 375 €). Le service n'utilise qu'un port série et de l'Ethernet, les boutons étant EnOcean, aucune entrée TOR n'est employée, `io_backend.py` n'est même pas appelé. Trois gains au-delà du prix : le Gate est livré sous **Debian**, ce qui **lève le point ouvert §12.9** (Mervis ou Linux) ; il offre **deux ports Ethernet**, donc une séparation physique OT/IT ; et 16 Go d'eMMC au lieu de 8. Total de l'architecture : 692 € au lieu de 867 € HT. | §2 étape 0.6, §3 kanban B8, BOM, comparatif |
| 2026-08-18 | Nomenclature de la carte AGV **extraite du projet KiCad** (57 composants placés) au lieu d'être estimée. Deux découvertes : l'étage de sortie est à **23 MOSFET IRF520** avec résistances de grille, le collecteur ouvert est fait par le matériel, donc le microcontrôleur doit être en **sortie poussée** (`x_open_drain: false`, corrigé ; une grille flottante mettrait le MOSFET dans un état indéterminé), et **aucune protection n'existe sur les 21 entrées Y**, ce qui confirme W1b. La carte est fabriquée et non réutilisée : le total passe de 738 € à 867 € HT. | §1.1 (109 tests), §1.4, §1.8, BOM, comparatif |
| 2026-08-18 | Ajout de [`../BOM.md`](../BOM.md) : nomenclature complète. La carte AGV coûte 0 € (elle est conservée) mais deux postes propres à cette architecture apparaissent : le harnais de raccordement (42 €) et une adaptation de niveaux conservatoire (0 à 45 €) tant que W1b n'est pas mesuré. Total ~738 € sur 10 ans, dont 461 € pour le seul poste UniPi. | §3 « Fait », journal |
| 2026-08-18 | Rangement du dossier : le projet KiCad de la carte d'origine est sous `../../materiel/AIO_AGV_Control_V5.0.1/`, la photo d'assemblage sous `hardware/photos/`, et `Planification_Architecture_WiFi_AGV.md` rejoint `docs/` pour aligner tous les dossiers d'architecture sur la même disposition. Les sauvegardes automatiques KiCad (35 archives, 3,6 Mo) sortent du suivi Git : elles sont régénérées à chaque ouverture du projet. | Liens, §3 « Fait », journal |
| 2026-08-14 | Ajout de [`../DEPLOY.md`](../DEPLOY.md) : procédure de déploiement en 11 phases, des mesures préalables au procès-verbal de recette. Met en tête les trois points irréversibles ou bloquants, sauvegarde des firmwares d'origine (sans laquelle il n'y a aucun retour arrière), niveaux du bus non mesurés, accord du service informatique. Inclut les commandes de sauvegarde `esptool`/`avrdude`, la configuration durcie de Mosquitto avec ACL par topic, dix essais de dégradation et une fiche de recette à viser. | §2 renvoie au runbook, §3 « Fait », journal |
| 2026-08-14 | Correction (analyse PCB) : **le L7806CV est l'ALIMENTATION de l'ATmega**, 24 V venant de CN64 A6/B6, abaissés à 6 V. Ce n'est donc ni un étage de sortie, ni un niveau de signal. Conséquence : les niveaux du bus redeviennent entièrement inconnus, l'amplitude des lignes Y (W1b) repasse BLOQUANT, et une question nouvelle apparaît (W1e), 6 V est le maximum absolu du datasheet de l'ATmega2560, à vérifier sur V_CC. Le mode collecteur ouvert est CONSERVÉ, avec une justification corrigée : il ne peut rien détruire, à défaut de connaître la topologie. Aucun changement de code, uniquement les justifications. | §1.8, kanban B2/B2c/B2d, étapes 0.4a et 0.4c |
| 2026-08-14 | ~~Correction : le rail 6 V (LM7806) serait sur l'étage de SORTIE~~, **infirmé le jour même par l'analyse PCB**, voir la ligne ci-dessus. Reste de cette étape : l'ajout du mode collecteur ouvert, qui garde sa valeur., pas sur les entrées. L'automate attend du 6 V là où l'ATmega sort 5 V. Ajout d'un mode **collecteur ouvert** (`bus.x_open_drain`, actif par défaut) : la broche tire à la masse ou passe en haute impédance, elle ne sort jamais de niveau haut, ce qui évite de remonter du courant dans la diode de protection si l'automate tire ses entrées à 6 V. W1b requalifié : ce n'est plus un risque de destruction des entrées, c'est un choix de topologie de sortie à confirmer par la mesure. | Compteurs (105 → 108 tests), §1.4, §1.8, kanban B2, étape 0.4a |
| 2026-08-14 | Intégration du **relevé de câblage SUB-D 25** fourni par le client. Le driver de bus AVR est réécrit : table bit à bit sur 11 ports au lieu de 3 ports contigus supposés, masquage obligatoire des 3 ports mixtes (PA/PB/PG), pull-ups paramétrables. §12.2, §12.6 et W1 passent à « relevé » ; W1b (amplitude des Y face aux entrées 5 V) devient le point bloquant le plus urgent. | Compteurs (101 → 105 tests), §1.4, §1.8, kanban B2/B2b, étapes 0.4a et 2 |
| 2026-08-14 | Création du dossier d'architecture Wi-Fi. Cœur métier repris du dossier SMS_EnOcean ; réécriture des deux firmwares de la carte V5.0.1 selon `Planification_Architecture_WiFi_AGV.md` : séquenceur et file déplacés sur l'ATmega, ESP32 en client Wi-Fi/MQTT, heartbeat de repli, protocole inter-MCU, JSON MQTT, driver de bus AVR, poste UniPi EnOcean→MQTT. | Document initial, 101 tests C++, 17 tests Python |

### Règle de tenue

À chaque modification du dossier :

1. compteur de tests (§1.1) si le nombre bouge ;
2. cartes déplacées dans le kanban (§3) ;
3. une ligne datée dans le journal ;
4. si un point du §12 ou un point W est relevé : mettre à jour
   `profiles/*.yaml` ou `board_ports.h`, cocher
   [`questions_ouvertes.md`](questions_ouvertes.md), sortir la carte de
   « Bloqué » ;
5. **si la modification touche le cœur métier** (séquenceur, file, protocole,
   simulateur), la reporter dans les autres dossiers d'architecture de
   `` : ils en portent une copie.

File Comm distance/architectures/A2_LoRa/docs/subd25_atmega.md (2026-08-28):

# SUB-D 25 ↔ ATmega2560 : table de câblage RELEVÉE

> **Source** : relevé de câblage fourni par le client. Ce n'est plus une
> hypothèse : c'est la table de référence.
> Source exécutable : [`../firmware/mega/src/board_ports.h`](../firmware/mega/src/board_ports.h).
> Toute correction se fait là, puis se recopie ici.

## Confection des nappes

Deux nappes de 25 fils, une par sens.

| | Connecteur côté MEGA | Côté AGV |
|---|---|---|
| **Entrées** (AGV → carte) | IDC SUB-D 25 **mâle** | cosses serties, CN62 / CN63 / CN64 |
| **Sorties** (carte → AGV) | IDC SUB-D 25 **femelle** | cosses serties, CN61 / CN62 / CN63 |

Les broches 1 et 14 de chaque SUB-D sont les masses (0 V).

---

## Alimentation : le rôle réel du L7806CV

Analyse du PCB : les fils 24 et 25 de la nappe d'entrée amènent **RP24B (24 V)**
depuis **CN64 A6 et B6**. Un **L7806CV** abaisse ce 24 V à **6 V**, qui alimente
l'**ATmega2560**.

Le 6 V est donc une **tension d'alimentation**, pas un niveau de signal. Il ne
dit rien, ni sur l'amplitude des lignes Y, ni sur ce qu'attendent les entrées de
l'automate.

### ⚠️ Point à vérifier sur le PCB : où arrive exactement ce 6 V ?

Trois cas, aux conséquences très différentes :

| Le 6 V arrive sur… | Conséquence |
|---|---|
| **V_CC de l'ATmega, directement** | 6,0 V est la **valeur maximale absolue** du datasheet, et la plage recommandée s'arrête à 5,5 V (4,5–5,5 V à 16 MHz). Un L7806 sort typiquement 5,76 à 6,24 V : le microcontrôleur peut donc fonctionner **au-delà de son maximum absolu** |
| Un second régulateur 5 V | Cas sain, rien à signaler |
| `Vin` d'une carte Arduino MEGA | 6 V est **sous** le minimum recommandé (7 V) pour le régulateur embarqué : avec ~1,1 V de chute, le rail 5 V peut s'affaisser |

**À mesurer** : la tension réelle sur la broche V_CC de l'ATmega, carte sous
tension. C'est une mesure de trente secondes qui écarte une question de
fiabilité à long terme.

### Ce que ça pourrait vouloir dire : hypothèse à confirmer

Si le 6 V alimente bien directement l'ATmega, c'est peut-être **délibéré** :
les sorties du microcontrôleur suivent V_CC, donc les lignes X sortiraient
naturellement du 0–6 V, et les entrées Y toléreraient jusqu'à ~6,5 V. Le
concepteur d'origine aurait ainsi adapté les niveaux du bus MEIDEN sans étage
de conversion.

C'est cohérent, mais ce n'est **pas** établi. Deux mesures le confirment ou
l'infirment : la tension V_CC, et l'amplitude d'une ligne Y.

---

## ⚠️ Niveaux du bus : ce qui reste inconnu

Le rôle du L7806 étant élucidé, **plus rien ne renseigne sur les niveaux du
bus** :

- **amplitude des lignes Y** (§12.1) : toujours inconnue. Le relevé les amène
  directement sur des broches d'ATmega. Mesurer sur `Y05` avant de brancher la
  nappe d'entrées, au-delà de V_CC + 0,5 V, l'entrée est détruite ;
- **topologie des entrées de l'automate** : tirées à une tension quelconque
  (la carte devrait alors seulement tirer à la masse), ou attendant un courant
  fourni par la carte ? Non déterminé.

### ✅ La topologie de sortie, elle, est connue

Le projet KiCad de la carte
([`../../../materiel/AIO_AGV_Control_V5.0.1/`](../../../materiel/AIO_AGV_Control_V5.0.1/))
montre **23 MOSFET N canal IRF520** en TO-220, attaqués par des résistances de
grille de 1 kΩ. Le collecteur ouvert est donc réalisé **par le matériel** : le
MOSFET tire la ligne de l'automate à la masse et ne sort jamais de niveau haut.

Conséquence sur le firmware : le microcontrôleur pilote une **grille**, pas la
ligne de l'automate. Il doit être en **sortie poussée**
(`bus.x_open_drain: false`, valeur du profil). Le mode collecteur ouvert côté
microcontrôleur laisserait la grille **flottante** à l'état actif : un MOSFET à
grille flottante peut conduire partiellement, ce qui est le pire état possible
sur un étage de puissance.

L'inversion est faite par le MOSFET : microcontrôleur à l'état haut → MOSFET
passant → ligne automate tirée à 0 V.

⚠️ **23 MOSFET pour 22 voies X** : `T13` est absent de la numérotation. À
vérifier au schéma : voie de réserve, ou signal supplémentaire non identifié.

Le mode collecteur ouvert reste implémenté et testé : il redevient le mode sûr
pour toute carte dépourvue d'étage de sortie.

---

## Ce que le relevé confirme

Deux points ouverts du brief sont **tranchés** par cette table :

- **§12.2, brochage SUB-D** : les connecteurs AGV sont CN61 à CN64, et non le
  jeu CN61/62/63 seul. La divergence des deux tables qui circulaient est levée.
- **§12.6, ordre des bits** : les libellés constructeur donnent les poids sans
  ambiguïté (`Station/Marker x1` … `x512`, `Speed x1` … `x8`). L'ordre codé dans
  `kDefaultLayout` est confirmé, il n'est plus provisoire.

---

## Entrées : SUB-D 25 mâle (AGV → carte)

| Fil | SUB-D | MEGA | Port AVR | Signal | Connecteur | Broche | Description |
|---:|---:|---|---|---|---|---|---|
| 1 | 1 | GND | - | 0 V | CN62 | B2 | masse |
| 2 | 14 | GND | - | 0 V | CN62 | A2 | masse |
| 3 | 2 | D11 | **PB5** | `Y03` | CN62 | B3 | défaut (error lamp flag) |
| 4 | 15 | D15 | **PJ0** | `Y05` | CN62 | A3 | moving flag |
| 5 | 3 | D9 | **PH6** | `Y10` | CN63 | B1 | in station flag |
| 6 | 16 | D17 | **PH0** | `Y11` | CN63 | A1 | vitesse courante bit 1 |
| 7 | 4 | D7 | **PH4** | `Y12` | CN63 | B2 | vitesse courante bit 2 |
| 8 | 17 | D19 | **PD2** | `Y13` | CN63 | A2 | vitesse courante bit 3 |
| 9 | 5 | D5 | **PE3** | `Y14` | CN63 | B3 | vitesse courante bit 4 |
| 10 | 18 | D21 | **PD0** | `Y15` | CN63 | A3 | écho aiguillage |
| 11 | 6 | D3 | **PE5** | `Y20` | CN63 | B14 | écho sens (avant/arrière) |
| 12 | 19 | D23 | **PA1** | `Y21` | CN63 | A14 | pas de destination programmée |
| 13 | 7 | D2 | **PE4** | `Y22` | CN63 | B15 | instruction reading complete |
| 14 | 20 | A1 | **PF1** | `Y23` | CN63 | A15 | position ×1 |
| 15 | 8 | D4 | **PG5** | `Y24` | CN63 | B16 | position ×2 |
| 16 | 21 | A3 | **PF3** | `Y25` | CN63 | A16 | position ×4 |
| 17 | 9 | D6 | **PH3** | `Y26` | CN63 | B17 | position ×8 |
| 18 | 22 | A5 | **PF5** | `Y27` | CN63 | A17 | position ×16 |
| 19 | 10 | D8 | **PH5** | `Y30` | CN64 | B1 | position ×32 |
| 20 | 23 | A7 | **PF7** | `Y31` | CN64 | A1 | position ×64 |
| 21 | 11 | D10 | **PB4** | `Y32` | CN64 | B2 | position ×128 |
| 22 | 24 | A9 | **PK1** | `Y33` | CN64 | A2 | position ×256 |
| 23 | 12 | D12 | **PB6** | `Y34` | CN64 | B3 | position ×512 |
| 24 | 25 | 24 V → L7806CV → 6 V | - | RP24B | CN64 | A6 | **alimentation de l'ATmega** |
| 25 | 13 | 24 V → L7806CV → 6 V | - | RP24B | CN64 | B6 | **alimentation de l'ATmega** |

Rappel de numérotation **octale** : après `Y27` vient `Y30`. La plage
`Y23`…`Y34` compte **10** signaux, pas 12, et les libellés `×1` à `×512` le
confirment.

## Sorties : SUB-D 25 femelle (carte → AGV)

| Fil | SUB-D | MEGA | Port AVR | Signal | Connecteur | Broche | Description |
|---:|---:|---|---|---|---|---|---|
| 1 | 1 | GND | - | 0 V | CN61 | B7 | masse |
| 2 | 14 | GND | - | 0 V | CN61 | A7 | masse |
| 3 | 2 | D39 | **PG2** | `X96` | CN61 | B6 | destination ×1 |
| 4 | 15 | D49 | **PL0** | `X97` | CN61 | A6 | destination ×2 |
| 5 | 3 | D33 | **PC4** | `X94` | CN61 | B5 | type de donnée (station ou marqueur) |
| 6 | 16 | D50 | **PB3** | `X95` | CN61 | A5 | frein externe |
| 7 | 4 | D26 | **PA4** | `X92` | CN61 | B4 | instruction data input switch |
| 8 | 17 | D47 | **PL2** | `X93` | CN61 | A3 | write input data switch (strobe) |
| 9 | 5 | D31 | **PC6** | `X90` | CN61 | B3 | vitesse ×4 |
| 10 | 18 | D46 | **PL3** | `X91` | CN61 | A3 | vitesse ×8 |
| 11 | 6 | D41 | **PG0** | `XA0` | CN62 | B6 | destination ×4 |
| 12 | 19 | D44 | **PL5** | `XA1` | CN62 | A6 | destination ×8 |
| 13 | 7 | D35 | **PC2** | `XA2` | CN62 | B7 | destination ×16 |
| 14 | 20 | D45 | **PL4** | `XA3` | CN62 | A7 | destination ×32 |
| 15 | 8 | D28 | **PA6** | `XA4` | CN62 | B8 | destination ×64 |
| 16 | 21 | D37 | **PC0** | `XA5` | CN62 | A8 | destination ×128 |
| 17 | 9 | D29 | **PA7** | `XA6` | CN62 | B9 | destination ×256 |
| 18 | 22 | D24 | **PA2** | `XA7` | CN62 | A9 | destination ×512 |
| 19 | 10 | D43 | **PL6** | `X82` | CN63 | B5 | standby release (départ) |
| 20 | 23 | D25 | **PA3** | `X83` | CN63 | A5 | standby stop |
| 21 | 11 | D22 | **PA0** | `X84` | CN63 | B6 | changement d'aiguillage |
| 22 | 24 | D51 | **PB2** | `X85` | CN63 | A6 | changement de sens |
| 23 | 12 | D30 | **PC7** | `X86` | CN63 | B7 | vitesse bit 1 |
| 24 | 25 | D48 | **PL1** | `X87` | CN63 | A7 | vitesse bit 2 |
| 25 | 13 | D27 | PA5 | - | : | - | **non connecté** |

---

## Répartition sur les ports : ce qui contraint le firmware

Les 43 signaux occupent **onze ports**, par bits épars.

| Port | Sorties X | Entrées Y | |
|---|---|---|---|
| **PORTA** | bits 0, 2, 3, 4, 6, 7 | **bit 1** (`Y21`) | ⚠️ **mixte** |
| **PORTB** | bits 2, 3 | **bits 4, 5, 6** | ⚠️ **mixte** |
| PORTC | bits 0, 2, 4, 6, 7 | - | |
| PORTD | - | bits 0, 2 | |
| PORTE | - | bits 3, 4, 5 | |
| PORTF | - | bits 1, 3, 5, 7 | |
| **PORTG** | bits 0, 2 | **bit 5** (`Y24`) | ⚠️ **mixte** |
| PORTH | - | bits 0, 3, 4, 5, 6 | |
| PORTJ | - | bit 0 | |
| PORTK | - | bit 1 | |
| PORTL | bits 0 à 6 | - | |

### Conséquence 1 : trois ports mixtes

`PORTA`, `PORTB` et `PORTG` portent des sorties X **et** des entrées Y. Toute
écriture de `DDRx` ou de `PORTx` doit être **masquée**. Un `DDRA = 0xFF`
mettrait `D23` (`Y21`) en sortie face à une sortie de l'automate : conflit
électrique franc.

Le driver applique donc partout un `|= masque_X` / `&= ~masque_Y`, et une
lecture-modification-écriture sur les données. C'est vérifié par le test
`avr_les_ports_mixtes_ne_voient_pas_leur_direction_ecrasee`.

### Conséquence 2 : la pose n'est plus strictement simultanée

Les sorties occupent 5 ports → **5 écritures** par pose complète, ~0,3 µs à
16 MHz. Les 10 bits d'adresse s'étalent sur 4 ports (`PORTA`, `PORTC`, `PORTG`,
`PORTL`) → ~0,25 µs entre le premier et le dernier bit posé.

Ce n'est pas la simultanéité stricte d'un `PORTA = x`, mais :

| Interface | Pose des 22 lignes | Écart entre premier et dernier bit |
|---|---|---|
| **Ce câblage** | ~0,3 µs | ~0,25 µs |
| 4× MCP23017 (I²C) | ~150 µs | ~25 µs |
| `t_setup` attendu | - | 200 µs (PROVISOIRE §12.4) |

L'écart résiduel est **800 fois plus petit** que le `t_setup` provisoire. Il
reste à confirmer au banc que l'automate ne voit rien passer d'incohérent : la
mesure se lit dans `port_writes_per_pose()` et à l'analyseur logique.

---

## Contrôle du câblage avant mise en service

Même avec une table relevée, un contrôle s'impose : une nappe peut être sertie à
l'envers, et un mot d'adresse mal câblé **n'échoue pas** : il envoie l'AGV à la
mauvaise station.

**Automate DÉBRANCHÉ. Les deux SUB-D 25 déconnectés.**

1. Flasher le firmware MEGA (`pio run -e mega -t upload`).
2. Console série USB à 115 200 bauds.
3. Envoyer `d` → le firmware annonce `# DECOUVERTE bit X=0` puis change d'index
   toutes les 3 secondes, une seule sortie active à la fois.
4. Pour chaque index, vérifier au multimètre que la broche SUB-D attendue par la
   table ci-dessus est bien celle qui bouge.
5. Envoyer `n` pour revenir en mode normal.

Pour les entrées, forcer un signal Y depuis l'automate en mode manuel et lire
l'état renvoyé par la commande `GetState` de la liaison série
(`tools/decode_link.py` décode la trame).

Toute divergence se corrige dans
[`board_ports.h`](../firmware/mega/src/board_ports.h), puis `make test`.

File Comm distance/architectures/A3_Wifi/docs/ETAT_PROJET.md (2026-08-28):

# État du projet : architecture Wi-Fi (carte V5.0.1 conservée)

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

---

## 1. Ce qui est fait

### 1.1 Vue d'ensemble

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

```bash
python3 tools/genconfig.py profiles/default.yaml \
        firmware/common/config/generated_profile.h
make test
```

### 1.2 Répartition des rôles : la décision structurante

Détail et justification : [`carte_v5_architecture.md`](carte_v5_architecture.md).

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

### 1.3 Repli de sécurité : le mécanisme central

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

Vérifié par 6 tests dédiés, dont :

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

### 1.4 Firmware ATmega2560 (réécrit)

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

### 1.5 Firmware ESP32 (réécrit)

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

### 1.6 Liaison inter-MCU

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

### 1.7 Poste fixe UniPi

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

### 1.8 Ce qui n'a **pas** pu être vérifié ici

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

---

## 2. Déploiement en conditions réelles

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

### Étape 0 : Prérequis bloquants (planification §3)

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

### Étape 1 : Poste de développement

```bash
pip install platformio
cd poste-unipi && pip install -e '.[dev,mqtt,enocean_serial]' && cd ..

python3 tools/genconfig.py profiles/default.yaml \
        firmware/common/config/generated_profile.h
make test
cd poste-unipi && python3 -m pytest tests -q && cd ..
```

### Étape 2 : Contrôle du brochage SUB-D, automate débranché

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

```bash
pio run -e mega -t upload        # via l'ICSP ou le bootloader, selon la carte
pio device monitor -b 115200     # puis envoyer 'd'
```

Reporter le relevé dans `board_ports.h` et `profiles/default.yaml`, régénérer,
relancer `make test`.

### Étape 3 : Renseigner le profil

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

### Étape 4 : Infrastructure (planification §4)

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

### Étape 5 : Flash des deux firmwares

```bash
pio run -e mega  -t upload       # ATmega2560 : séquenceur + file
pio run -e esp32 -t upload       # ESP32 : Wi-Fi + MQTT + heartbeat
```

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

### Étape 6 : Poste fixe UniPi

```bash
sudo useradd -r -s /usr/sbin/nologin agv
sudo mkdir -p /opt/agv /etc/agv /var/lib/agv
sudo python3.11 -m venv /opt/agv/venv
sudo /opt/agv/venv/bin/pip install './poste-unipi[mqtt,enocean_serial]'
sudo cp poste-unipi/poste.example.toml /etc/agv/poste.toml
sudo $EDITOR /etc/agv/poste.toml       # port TCM 515, broker, identifiants
sudo cp poste-unipi/systemd/agv-poste.service /etc/systemd/system/
sudo systemctl enable --now agv-poste
journalctl -u agv-poste -f
```

### Étape 7 : Mise en service

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

### Diagnostic sur site

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

---

## 3. Kanban

### 🔴 Bloqué : relevé ou décision client

| # | Tâche | Débloqué par |
|---|---|---|
| B1 | Renseigner `t_setup_us` et les timeouts `Y22`/`Y05`/`Y10` | Relevé à l'analyseur logique (0.4, §12.4-12.5) |
| ~~B2~~ | ~~Qualifier l'amplitude des lignes Y~~ | ✅ **vérifié par le client le 2026-08-21** |
| B2c | Confirmer la topologie de l'étage de sortie (`x_open_drain`) | Mesure du tirage côté automate (W1d) |
| B2d | Vérifier la tension V_CC de l'ATmega | 6 V = maximum absolu du datasheet (W1e) |
| B2b | Trancher les pull-ups internes sur les Y | Sorties automate à collecteur ouvert ou poussées ? (W1c) |
| B3 | Figer la polarité PNP/NPN | Mesure sur l'automate (§12.3) |
| B4 | Recaler le format `/agvdump` | Sortie réelle de la V5.0.1 (§12.6, §3.3) |
| B5 | Paramètres réseau et MQTT | Accord du service informatique (0.1, W5, W6) |
| ~~B6~~ | ~~Confirmer l'UART ESP32 ↔ ATmega~~ | ✅ **relevé au KiCad** : SoftwareSerial D52/D53, 38 400 bd |
| B6b | Vérifier au banc la tenue de `SoftwareSerial` à 38 400 bauds sous charge du séquenceur | L'émission logicielle masque les interruptions pendant chaque octet |
| B7 | Décider de la bande 2,4 GHz vs bi-bande | Arbitrage 0.7 |
| B2e | ⚠️ **Trancher l'étage de sortie** : `IRF520` (hors spec à 5 V), `IRL520` (logic-level, même brochage) ou `ULN2803A` | Le PCB est-il déjà fabriqué ? (analyse `BOM.md`) |
| B2f | Décider si l'isolation galvanique est requise : le `TDN 5-2411WISM` isolé cohabite avec des MOSFET à masse commune | Arbitrage client ; ~22 € en jeu (analyse `BOM.md`) |
| ~~B8~~ | ~~Runtime de l'UniPi~~ | **LEVÉ** si le Gate G100 est retenu : livré sous Debian |
| B9 | Voyant d'accusé opérateur | Décision client (planification §3.6) |

### 🟡 À faire, sans dépendance externe

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

### 🔵 Backlog

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

### ✅ Fait

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

---

## 4. Journal des mises à jour

| Date | Modification | Impact |
|---|---|---|
| 2026-08-28 | **Fusion des deux variantes LoRa et boutons rendus optionnels.** Elles ne se distinguaient que par la technologie du bouton : les boutons étant devenus optionnels, cette distinction ne définissait plus une architecture. `A2_Hybride` et `A3_LoRa` deviennent **`A2_LoRa`**, l'ancienne `A4_Wifi` devient **`A3_Wifi`** pour garder une numérotation continue. **Les boutons sortent des nomenclatures** : le planning seul fait rouler l'AGV, et leur choix reste ouvert, indépendant de l'architecture. Disparaissent avec eux le point de bascule entre variantes et les tableaux « coût par station », qui ne mesuraient que des boutons. Le poste ESP32 de l'ancienne A2 est supprimé (le poste est Linux), ainsi que le décodeur ESP3 en C++ de ce dossier, celui du poste étant en Python dans le banc. **Le banc EnOcean est conservé** : il validera les `PTM 210` si l'option est retenue. Trois architectures, un seul critère de choix : la liaison du poste vers l'AGV. A2 = 417 €, A3 = 592 €, A1 = 426 € plus 96 €/an. | arborescence, BOM, comparatif |
| 2026-08-28 | **Modèle d'architecture commun** : boutons d'appel optionnels, **poste central** hébergeant l'API de planning et recevant les appels, carte AGV Control, AGV. Les quatre architectures ne diffèrent plus que par la technologie de chaque liaison ([`ARCHITECTURE_COMMUNE.md`](../../../../docs/ARCHITECTURE_COMMUNE.md)). Trois conséquences. **A3 gagne un poste** (UniPi Lite 1.1, +209 € HT) et **perd son argument principal**, l'absence d'infrastructure ; elle conserve le bouton authentifié et l'accusé visuel. **Les postes ESP32 de A1 et A2 passent sous Linux** : héberger une API web, un planning persistant et un journal sur un microcontrôleur coûte trop en logiciel. **Le Timer quitte la carte AGV** pour le poste, ce qui fait disparaître le DS3231, la contrainte NVS et le serveur web à rendre permanent. Les quatre solutions se tiennent désormais entre **525 et 700 € HT** : le coût cesse d'être discriminant. ⚠️ **A2 et A3 ne sont plus séparées que par 19 € et le type de bouton** : question ouverte au client dans `COMPARAISON.md`. | les 4 architectures, BOM, comparatif |
| 2026-08-27 | **Tirets cadratins retirés de tout le dépôt** sur demande du client : 2318 occurrences, 360 fichiers, documentation, commentaires de code, chaînes affichées et gabarits web. Remplacement **contextuel** plutôt qu'uniforme : deux-points quand la suite explique, virgule après une liaison (*et, mais, donc, dont, notamment*), parenthèses pour une incise complète, trait d'union simple pour une valeur absente dans un tableau. Deux défauts corrigés au passage : le générateur produisait « Nomenclature : A3 : LoRa » (double ponctuation, le titre portant déjà son code), et le libellé de plage « Numérotation A1-A3 » avait vu sa borne basse renumérotée par mes permutations successives A1/A2 puis A2/A3. Contrôles passés : fidélité `agvdump`, conformité du thème, 470 + 53 + 19 tests. | tout le dépôt |
| 2026-08-27 | **Thème unifié sur toutes les interfaces du dépôt**, fond blanc, texte noir, bleu outremer, logo AIO : les six IHM (4 supervisions d'architecture, banc EnOcean, planning) partageaient jusqu'ici **trois palettes différentes**, deux sombres et une claire. La feuille vit une seule fois dans `docs/theme/theme.css` ; chaque interface en porte une copie (dossiers livrables seuls, et le banc part en `rsync` sur une UniPi). `outils/theme.sh` propage l'original et **signale les copies qui ont dérivé**, même garde que pour le rendu `agvdump`. Les `style.css` ne gardent que le spécifique. Deux défauts trouvés au rendu : le serveur du banc planning servait **tout** en `text/html`, donc la feuille était ignorée ; et les notifications recouvraient l'en-tête. Le banc EnOcean passe en **v1.2.0** pour que le contrôle de version du déploiement signale une copie périmée. | 6 interfaces, thème, outils |
| 2026-08-26 | **Banc EnOcean v1.1.0, la fenêtre d'ajout refusait toujours de se fermer.** Le correctif CSS précédent était juste mais ne pouvait pas suffire : la visibilité de la fenêtre reposait sur l'attribut `hidden`, que **toute** règle de feuille déclarant `display` écrase. Elle est désormais portée par un **style en ligne** posé par `afficherModale()`, un style en ligne l'emporte sur toute règle sans `!important`, **y compris sur une feuille périmée servie par le cache**. La feuille déclare `display: none` par défaut, et l'état initial est posé explicitement au démarrage du script. Deux causes systémiques traitées avec : le serveur envoie `Cache-Control: no-cache`, et `deployer.sh` remplace la copie manuelle, `rsync --delete`, redémarrage, puis **contrôle que la version servie est celle du dépôt**. La version s'affiche dans le bandeau. Une copie déployée périmée donne les symptômes du défaut qu'elle ne contient pas encore : c'est ce qui a coûté un aller-retour. | banc EnOcean |
| 2026-08-26 | **Banc EnOcean, deux défauts corrigés après essai sur la UniPi.** (1) La fenêtre d'ajout restait affichée en permanence : `.voile` déclarait `display: flex`, et **la moindre règle d'auteur déclarant `display` bat l'attribut `hidden`** du HTML, qui n'est qu'un `display: none` de la feuille par défaut. Une règle `[hidden] { display: none !important }` rétablit l'attribut pour tout le document. (2) L'écoute d'apprentissage était armée **une fois pour trente secondes** : passé ce délai un appui repartait en « bouton inconnu » au lieu d'alimenter le formulaire. Elle est désormais **renouvelée tant que la boîte d'ajout est ouverte**, fenêtre courte de 20 s réarmée toutes les 8 s, pour qu'un navigateur qui meurt éteigne l'écoute seul. L'identifiant capté est en outre déposé **dans le champ de saisie**, donc visible et corrigeable, et un remplacement est signalé par un flash, un remplacement silencieux ferait nommer le mauvais bouton. 19 tests. | banc EnOcean |
| 2026-08-26 | **Réorganisation du dépôt par NATURE d'objet.** `architectures/` (les 4 solutions), `bancs/` (les essais matériels), `materiel/` (les projets KiCad), `docs/` (brief et comparatif), `outils/` (scripts). Le dossier `CarteComm/` disparaît. **Le matériel n'est plus dupliqué** : une carte, un projet, un seul endroit, trois copies divergentes de la V6.0 avaient déjà coexisté, dont une que KiCad avait recréée à un chemin renommé, et il a fallu comparer les schémas pour trouver la vivante (celle du 26 août, avec l'embase J3 et les Gerbers). Le **brief** passe de 4 copies à 1. Les **bancs LoRa sortent de `A2_LoRa/test/`** pour rejoindre `bancs/lora/`, à la même forme que le banc EnOcean ; `test/native/` ne garde que les tests unitaires. Chaque banc a désormais son `README.md` **et** son `DEPLOY.md` avec une recette et les résultats attendus. `outils/exporter_architecture.sh` reconstitue une architecture autonome dans un zip, la zippabilité est payée à l'export, plus tous les jours. Le générateur de nomenclatures n'a plus de chemin absolu. **2 Mo de redondance supprimés.** | arborescence, tous les renvois |
| 2026-08-26 | **Banc d'essai EnOcean** ajouté dans `../../banc_enocean/` : service web déployable sur une UniPi E413 avec dongle USB. Enregistre les `PTM 210`, les **détecte à l'appui** ou par saisie de l'identifiant, et ouvre une fenêtre verte à chaque pression, nom, code, heure, niveau reçu. Un bouton non enregistré ouvre une fenêtre ambre plutôt que d'être ignoré. Bibliothèque standard seule hors `pyserial`, flux SSE, registre JSON. Le banc **ne dépend d'aucune architecture** : il sert à valider les boutons avant que le choix ne soit tranché. 17 tests sans matériel, dont la déduplication des **trois** sous-télégrammes et le rejet du relâchement, sans quoi un appui en afficherait six. | banc partagé A1/A2/A3 |
| 2026-08-25 | **La passerelle MQTT est remplacée par une passerelle LoRa.** `GatewayApp` publiait sur des topics et dépendait d'`IMqttPublisher` : il n'avait rien à faire dans une architecture sans broker. `LoraGatewayApp` le remplace, trames applicatives de 9 octets sur `ITransport`, accusé par la même voie, idempotence `(node_id, seq)` en table locale, et le **budget de rapport cyclique appliqué aux accusés** puisqu'un récepteur qui acquitte est un émetteur. Le firmware ESP32 est réécrit : plus de Wi-Fi STA ni de client MQTT, mais SPI + `Sx1276Radio` + `LoraTransport`, avec le brochage relevé au KiCad dans `board_pins.h`. `MqttConfig` et `WifiConfig` quittent le profil, la section `lora:` y entre, `aes_enabled` passe à **true**, sans TLS, le chiffrement applicatif est la seule protection de la liaison. Le champ `mqtt_up` d'`/agvdump` est **conservé** : c'est un contrat d'atelier (§3.3), il porte désormais l'état radio. **Kanban LG1 soldé.** | firmware, profils, tests |
| 2026-08-25 | ⚠️ **Deux défauts trouvés en écrivant les tests.** (1) La détection de silence de l'ATmega utilisait `0` comme sentinelle « jamais reçu », alors que c'est un instant valide au démarrage : elle était inopérante pendant les premières millisecondes. Corrigé par un drapeau explicite. (2) Le `Makefile` ne suivait **pas les dépendances d'en-têtes** : modifier une classe ne recompilait pas ses utilisateurs, et l'on reliait des objets compilés contre deux versions de la même classe, un test échouait sans qu'aucune erreur ne soit signalée. `-MMD -MP` ajouté aux **quatre** Makefile. | firmware, Makefile |
| 2026-08-25 | **La carte LoRa est la `AIO_AGV_Control_V6.0`, et elle est FABRIQUÉE.** Le diff des deux projets KiCad est sans ambiguïté : 58 empreintes contre 57, **un seul écart, le `RFM95W-868S2`**, tout le reste est identique au composant près. La radio est intégrée, câblée sur le SPI libre de l'ESP32 : ni carte fille, ni câblage volant. Les nomenclatures chiffraient jusqu'ici une V5.0.1 **réutilisée à 0 €** augmentée d'une carte fille à 18 € ; c'était une hypothèse de travail, remplacée par la nomenclature réelle à **111,15 € HT**. Conséquence assumée : **A3 passe de 208 à 329 €** et **A2 de 307 à 428 €** accessoires compris. Trois analyses devenues fausses sont réécrites, « réutiliser la carte existante », la question des optocoupleurs (la V6.0 a des MOSFET, pas de `PC847`) et le choix `shift595`. La table d'équivalences, jusqu'ici partagée, devient propre à chaque architecture : elle listait des composants absents de la carte concernée. | BOM, README, COMPARAISON |
| 2026-08-25 | **A2 et A3 permutés** : l'hybride EnOcean + LoRa devient **A2**, le LoRa pur devient **A3**, l'hybride a été étudié avant. Les dossiers suivent : `A3_Hybride/` → `A2_LoRa/` et `A2_LoRa/` → `A2_LoRa/`, ainsi que les documents de référence. Chaque dossier ne garde désormais **que sa propre spécification** : la copie étrangère héritée de la duplication est retirée. Le brief et l'index racine sont réordonnés pour se lire A1, A2, A3, A3. **Les variables du générateur cessent d'encoder un numéro d'architecture**, `bouton_a1` devient `bouton_pile`, `poste_a3` devient `poste_enocean`, `a1_ht` devient `ht_lora_pur` : c'est ce qui faisait revenir ce travail à chaque permutation. `subd25_atmega.md` reste exclu, `A2`/`A3` y désignant des broches de connecteur. | arborescence, BOM, brief, README |
| 2026-08-25 | **Réorganisation : un dossier par ARCHITECTURE et non plus par mode de communication.** `SMS_EnOcean/` → `A1_Cellulaire/`, `Wifi/` → `A3_Wifi/`, `LoRa/` → `A2_LoRa/`, et **`A2_LoRa/` est créé**. A3 et A2 étaient jusqu'ici un dossier de sources non autonome : ils reçoivent le cœur métier de A3 (c'est lui qui porte le duo MEGA + ESP32 de la carte V6.0, pas le firmware mono-ESP32 de A1) plus le transport LoRa, et A2 y ajoute le décodage ESP3 et le poste fixe. **Les quatre dossiers compilent et testent seuls** : 112, 119, 130 et 109 tests. Côté matériel, `AIO_AGV_Control_V6.0` quitte A3 pour A3 et A2 : le relevé KiCad montre que c'est la V5.0.1 **plus un `RFM95W-868S2`** (58 empreintes contre 57), câblé `NSS`→`IO5`, `SCK`→`IO18`, `MISO`→`IO19`, `MOSI`→`IO23`, `DIO0`→`IO26`, exactement le brochage supposé. ⚠️ **`RESET` n'est pas câblée**, `kPinReset` passe à `0xFF` et une carte de kanban est ouverte. ⚠️ Dette assumée : le firmware ESP32 de A3 et A2 porte encore la passerelle MQTT héritée de A3, à remplacer par un `LoraGatewayApp` (kanban LG1). | arborescence, BOM, README, journaux |
| 2026-08-25 | **A1 et A3 permutés** : le cellulaire devient **A1**, le LoRa homogène devient **A3**, la numérotation suit désormais l'ordre chronologique d'étude, le SMS ayant précédé le LoRa. A2 (hybride) et A3 (Wi-Fi) sont inchangés. Permutation appliquée à 10 fichiers, dont **le brief**, dont la table des architectures est aussi réordonnée ; les deux copies restent identiques. Les documents de référence sont renommés (`Archi_1_Cellulaire_SMS_LTE-M.md` et `Archi_2a_LoRa_P2P_homogene.md`) et leurs six renvois suivis. **Deux faux positifs protégés** : le repère KiCad `Mega2560 Pro (A1)`, et l'intégralité de `subd25_atmega.md`, où `A1`/`A3` désignent des broches de connecteur et non des architectures. | brief, BOM, README, COMPARAISON, DEPLOY |
| 2026-08-25 | **Numérotation A1–A3 rendue explicite dans les nomenclatures.** Le retrait des accessoires couvrait déjà les quatre architectures (42 lignes), mais seules A3 et A2 portaient leur code : les titres, les sections et les blocs Total nomment désormais **A1** (cellulaire) et **A3** (Wi-Fi) au même titre. `README.md` gagne une colonne `Code` et `COMPARAISON.md` complète ses libellés. `tools/prix_a_completer.md` est aligné : 7 lignes d'accessoires retirées, section « Boîtiers » supprimée, section 2 renommée « Radio », et une **enveloppe de sourcing** (~1 630 € HT) ajoutée, explicitement présentée comme une borne d'effort de recherche et **non un budget**, puisqu'elle additionne des alternatives qui s'excluent. | BOM, README, COMPARAISON, feuille de sourcing |
| 2026-08-25 | **Nomenclatures resserrées sur les composants déterminants.** Les accessoires arbitrables selon le budget (antennes, boîtiers, coffrets, enveloppes murales, câbles, plaques gravées) sont retirés de l'affichage et des sous-totaux : 36 lignes, qui se substituent librement d'un fournisseur à l'autre et n'engagent aucun choix de conception. Chaque `BOM.md` s'ouvre désormais sur un **bloc Total** rappelant, par variante, le montant des accessoires écartés, sans quoi un total amputé se lirait comme un coût d'achat complet. Les définitions restent dans `tools/generer_bom.py`, marquées `core=False`. ⚠️ `README.md` et `COMPARAISON.md` continuent de raisonner **accessoires compris** : comparer des architectures sans leurs boîtiers fausserait le classement. Le point de bascule A3/A2 est d'ailleurs devenu **calculé** au lieu d'être asséné, il passe de 8 à 9 stations, et deux coûts par station encore codés en dur ont été branchés sur les sections. | BOM, README, COMPARAISON |
| 2026-08-22 | **Essais radio LoRa** ajoutés dans `../../A2_LoRa/test/`, en deux sous-dossiers `esp32/` et `unipi/`, chacun avec un essai d'émission et un de réception. Les quatre combinaisons sont possibles ; les deux croisées sont celles qui comptent, car elles seules éprouvent l'interopérabilité. Les deux côtés parlent la **trame applicative du projet**, et `test_interop_trame.py` (le seul essai qui tourne sans matériel) compile le codec C++ du cœur pour vérifier que le portage Python encode **octet pour octet la même chose** : 6 vecteurs, extension d'horodatage comprise, 0 écart. Le budget de rapport cyclique est appliqué des deux côtés, accusés compris. | `LoRa/test/`, journal |
| 2026-08-21 | ⚠️ **Correction de firmware, la liaison inter-MCU n'est pas un UART matériel.** Le relevé du projet KiCad montre `ESP32 IO17` → `MEGA D52` en direct, et `MEGA D53` → pont 2,2 k/4,7 k → `ESP32 IO16`. Or D52/D53 ne sont pas des broches d'UART sur le MEGA, et **ses trois UART sont inutilisables** : leurs broches de réception portent `Y13` (D19/PD2), `Y11` (D17/PH0) et `Y05` (D15/PJ0). Le `Serial1.begin()` que contenait `firmware/mega/src/main.cpp` aurait mis **Y13 en sortie contre la sortie de l'automate**. Passage en `SoftwareSerial` sur D52/D53 et **abaissement à 38 400 bauds**, 115 200 n'étant pas tenable en émulation logicielle sur AVR. **W2 est clos.** | §1.6, W2, `profiles/default.yaml`, 109 tests toujours verts |
| 2026-08-21 | **W1b clos** : le client a vérifié l'amplitude des lignes Y, la connexion directe sur broches d'ATmega est confirmée compatible. La valeur mesurée reste à consigner dans `questions_ouvertes.md` pour la traçabilité. | W1b, kanban B2 |
| 2026-08-21 | Troisième variante d'interface bus chiffrée pour l'architecture LoRa : **`avr_port`**, alignée sur la topologie de la V5.0.1. Un `Mega2560 Pro` porte les 43 lignes sur ses broches, les 11 `PC847` disparaissent, et `avr_port_bus.cpp` (écrit et testé ici) se réutilise avec son relevé de câblage. 12 € HT de plus, une conception matérielle au lieu de deux. **Contrepartie : W1b devient strictement bloquant**, un optocoupleur encaisse 24 V, une broche d'ATmega non. La V5.0.1 relie pourtant ses 21 entrées Y directement depuis cinq ans, ce qui rend l'hypothèse « lignes en logique » très probable sans la démontrer. | BOM LoRa, W1b |
| 2026-08-21 | Colonne **`Lien d'achat`** ajoutée aux nomenclatures et à `tools/prix_a_completer.md`, en remplacement de la colonne `Source` qu'elle rend redondante. **RS est mis en tête partout**, y compris sur les références EnOcean et Unipi qu'il ne distribue habituellement pas : le catalogue évolue et une commande groupée chez un fournisseur référencé vaut souvent le surcoût unitaire. Ce sont des liens de **recherche sur la référence fabricant**, pas des fiches produit, le site de RS bloque l'accès automatisé, aucun numéro de stock n'a donc pu être vérifié. Des numéros inventés auraient produit des liens crédibles menant à la mauvaise pièce. | BOM, feuille de sourcing |
| 2026-08-20 | **Analyse critique de la carte routée** ajoutée à `BOM.md`. Trois points relevés sur le projet KiCad. (1) L'`IRF520` n'est **pas** un MOSFET logic-level : seuil spécifié de 2 à 4 V, `Rds(on)` garanti à Vgs = 10 V. Il conduit sous 5 V et convient aux quelques milliampères d'une entrée d'automate, mais hors conditions constructeur ; l'`IRL520` est une substitution sans reroutage, l'`ULN2803A` divise la surface par dix. (2) Le convertisseur **isolé** `TDN 5-2411WISM` (poste le plus cher de la carte) cohabite avec un étage de sortie à **masse commune** : l'isolation ne protège pas les signaux, et si elle ne visait qu'eux, un `TSR 1-2450` économise ~22 €. (3) Le 6 V du `L7806CV` reste au maximum absolu de l'ATmega alors qu'un 5 V propre existe déjà sur la carte. Aucun changement de nomenclature : ces trois points sont des **décisions**, pas des corrections. | §3 kanban B2e/B2f, BOM |
| 2026-08-18 | Poste fixe : l'automate UniPi est remplacé par une passerelle **Unipi Gate G100** (~200 € au lieu de 375 €). Le service n'utilise qu'un port série et de l'Ethernet, les boutons étant EnOcean, aucune entrée TOR n'est employée, `io_backend.py` n'est même pas appelé. Trois gains au-delà du prix : le Gate est livré sous **Debian**, ce qui **lève le point ouvert §12.9** (Mervis ou Linux) ; il offre **deux ports Ethernet**, donc une séparation physique OT/IT ; et 16 Go d'eMMC au lieu de 8. Total de l'architecture : 692 € au lieu de 867 € HT. | §2 étape 0.6, §3 kanban B8, BOM, comparatif |
| 2026-08-18 | Nomenclature de la carte AGV **extraite du projet KiCad** (57 composants placés) au lieu d'être estimée. Deux découvertes : l'étage de sortie est à **23 MOSFET IRF520** avec résistances de grille, le collecteur ouvert est fait par le matériel, donc le microcontrôleur doit être en **sortie poussée** (`x_open_drain: false`, corrigé ; une grille flottante mettrait le MOSFET dans un état indéterminé), et **aucune protection n'existe sur les 21 entrées Y**, ce qui confirme W1b. La carte est fabriquée et non réutilisée : le total passe de 738 € à 867 € HT. | §1.1 (109 tests), §1.4, §1.8, BOM, comparatif |
| 2026-08-18 | Ajout de [`../BOM.md`](../BOM.md) : nomenclature complète. La carte AGV coûte 0 € (elle est conservée) mais deux postes propres à cette architecture apparaissent : le harnais de raccordement (42 €) et une adaptation de niveaux conservatoire (0 à 45 €) tant que W1b n'est pas mesuré. Total ~738 € sur 10 ans, dont 461 € pour le seul poste UniPi. | §3 « Fait », journal |
| 2026-08-18 | Rangement du dossier : le projet KiCad de la carte d'origine est sous `../../materiel/AIO_AGV_Control_V5.0.1/`, la photo d'assemblage sous `hardware/photos/`, et `Planification_Architecture_WiFi_AGV.md` rejoint `docs/` pour aligner tous les dossiers d'architecture sur la même disposition. Les sauvegardes automatiques KiCad (35 archives, 3,6 Mo) sortent du suivi Git : elles sont régénérées à chaque ouverture du projet. | Liens, §3 « Fait », journal |
| 2026-08-14 | Ajout de [`../DEPLOY.md`](../DEPLOY.md) : procédure de déploiement en 11 phases, des mesures préalables au procès-verbal de recette. Met en tête les trois points irréversibles ou bloquants, sauvegarde des firmwares d'origine (sans laquelle il n'y a aucun retour arrière), niveaux du bus non mesurés, accord du service informatique. Inclut les commandes de sauvegarde `esptool`/`avrdude`, la configuration durcie de Mosquitto avec ACL par topic, dix essais de dégradation et une fiche de recette à viser. | §2 renvoie au runbook, §3 « Fait », journal |
| 2026-08-14 | Correction (analyse PCB) : **le L7806CV est l'ALIMENTATION de l'ATmega**, 24 V venant de CN64 A6/B6, abaissés à 6 V. Ce n'est donc ni un étage de sortie, ni un niveau de signal. Conséquence : les niveaux du bus redeviennent entièrement inconnus, l'amplitude des lignes Y (W1b) repasse BLOQUANT, et une question nouvelle apparaît (W1e), 6 V est le maximum absolu du datasheet de l'ATmega2560, à vérifier sur V_CC. Le mode collecteur ouvert est CONSERVÉ, avec une justification corrigée : il ne peut rien détruire, à défaut de connaître la topologie. Aucun changement de code, uniquement les justifications. | §1.8, kanban B2/B2c/B2d, étapes 0.4a et 0.4c |
| 2026-08-14 | ~~Correction : le rail 6 V (LM7806) serait sur l'étage de SORTIE~~, **infirmé le jour même par l'analyse PCB**, voir la ligne ci-dessus. Reste de cette étape : l'ajout du mode collecteur ouvert, qui garde sa valeur., pas sur les entrées. L'automate attend du 6 V là où l'ATmega sort 5 V. Ajout d'un mode **collecteur ouvert** (`bus.x_open_drain`, actif par défaut) : la broche tire à la masse ou passe en haute impédance, elle ne sort jamais de niveau haut, ce qui évite de remonter du courant dans la diode de protection si l'automate tire ses entrées à 6 V. W1b requalifié : ce n'est plus un risque de destruction des entrées, c'est un choix de topologie de sortie à confirmer par la mesure. | Compteurs (105 → 108 tests), §1.4, §1.8, kanban B2, étape 0.4a |
| 2026-08-14 | Intégration du **relevé de câblage SUB-D 25** fourni par le client. Le driver de bus AVR est réécrit : table bit à bit sur 11 ports au lieu de 3 ports contigus supposés, masquage obligatoire des 3 ports mixtes (PA/PB/PG), pull-ups paramétrables. §12.2, §12.6 et W1 passent à « relevé » ; W1b (amplitude des Y face aux entrées 5 V) devient le point bloquant le plus urgent. | Compteurs (101 → 105 tests), §1.4, §1.8, kanban B2/B2b, étapes 0.4a et 2 |
| 2026-08-14 | Création du dossier d'architecture Wi-Fi. Cœur métier repris du dossier SMS_EnOcean ; réécriture des deux firmwares de la carte V5.0.1 selon `Planification_Architecture_WiFi_AGV.md` : séquenceur et file déplacés sur l'ATmega, ESP32 en client Wi-Fi/MQTT, heartbeat de repli, protocole inter-MCU, JSON MQTT, driver de bus AVR, poste UniPi EnOcean→MQTT. | Document initial, 101 tests C++, 17 tests Python |

### Règle de tenue

À chaque modification du dossier :

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

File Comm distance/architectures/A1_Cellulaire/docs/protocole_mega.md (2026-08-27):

# Protocole inter-MCU ESP32 ↔ ATmega2560

Variante C du §4.4 (« ATmega2560 conservé »). Le MEGA garde ce qu'il fait mieux
que les alternatives : poser 22 lignes en un cycle (`PORTx = valeur`, < 1 µs,
strictement simultané).

## Principe

Le MEGA est un **organe de pose**, rien de plus. Il n'applique ni `t_setup`, ni
polarité, ni timeout, et ne connaît ni la file de courses ni le séquenceur.
Toute la logique (donc tous les paramètres du §12) reste dans l'ESP32.

Motif : si les deux firmwares portaient la même vérité (un `t_setup` ici, un
autre là), ils divergeraient au premier relevé et personne ne saurait lequel
fait foi.

## Liaison

UART, **500 000 bauds**, 8N1. `Serial1` côté MEGA, `UART_NUM_2` côté ESP32.

## Format

```
ESP32 -> MEGA : A5 | cmd | len | payload[len] | crc16_hi | crc16_lo
MEGA  -> ESP32: 5A | cmd | len | payload[len] | crc16_hi | crc16_lo
```

- CRC-16/CCITT-FALSE calculé sur `cmd | len | payload` (le SOF est exclu).
- Le SOF diffère dans chaque sens : une trame réfléchie ne peut pas être
  confondue avec une requête.
- Trame à CRC faux côté MEGA : **silence**. L'ESP32 gère le timeout et compte la
  désynchronisation (`MegaUartBus::desync_count()`), ce qui remonte dans
  `agvdump`.

## Commandes

| cmd | Nom | Requête | Réponse |
|---:|---|---|---|
| 0x01 | `SET_X` | 3 octets (22 bits utiles, poids forts en tête) | vide |
| 0x02 | `GET_Y` | vide | 3 octets (21 bits utiles) |
| 0x03 | `PULSE` | bit (1) + durée µs (2, big endian) | vide |
| 0x04 | `PING` | vide | version du firmware (1) |

## Exemple

`SET_X` avec le mot `0x0012_34` :

```
A5 01 03 00 12 34 <crc_hi> <crc_lo>
```

Réponse :

```
5A 01 00 <crc_hi> <crc_lo>
```

## Contraintes de temps

- L'ESP32 borne son attente de réponse (20 ms par défaut). Un MEGA muet fait
  échouer la pose, ce qui met le séquenceur en défaut `BUS_WRITE_ERROR`, jamais
  un blocage de la tâche bus.
- L'aller-retour complet à 500 kbauds coûte ~0,3 ms pour 8 octets dans chaque
  sens. C'est **le** coût de cette variante : la pose est instantanée, mais elle
  est précédée d'un aller-retour UART. À comparer aux ~150 µs des MCP23017 et
  aux ~3 µs des 74HC595, qui n'ont, eux, pas de liaison intermédiaire.

## Mise à zéro au démarrage

Le `setup()` du MEGA force `PORTA`, `PORTC` et les bits utiles de `PORTL` à zéro
**avant toute autre instruction**, conformément au §3.1. L'ESP32 le refait via
`writeX(0)` à l'issue du `PING` : la double sécurité est volontaire, les deux
cartes ne démarrent pas forcément en même temps.

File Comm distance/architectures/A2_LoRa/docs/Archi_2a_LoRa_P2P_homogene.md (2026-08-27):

# Architecture 1 : LoRa 868 MHz point-à-point privé (solution homogène)

> Document de référence : projet « Remplacement de la carte AIO AGV Control V5.0.1 »
> AGV MEIDEN à guidage magnétique, appel depuis boutons déportés vers points d'arrêt.

---

## 1. Fonction

Assurer la liaison radio bidirectionnelle **directe** entre les boutons d'appel et l'AGV, sans poste intermédiaire, sans infrastructure réseau et sans opérateur externe. Une seule technologie radio pour tout le système : LoRa 868 MHz en mode point-à-point privé.

Trois flux fonctionnels :

1. **Appel** : bouton *n* → AGV, « va à la station *n* »
2. **Accusé** : AGV → bouton, « ordre reçu, mis en file / refusé »
3. **Télémétrie** : AGV → tous les boutons (broadcast périodique), position, vitesse, défaut, batterie

---

## 2. Architecture générale

```
   BOUTON 1 (station 1)                                    AGV MEIDEN
 ┌────────────────────────┐                     ┌──────────────────────────────────┐
 │ Bouton IP65            │                     │  ESP32-WROOM-32E                 │
 │      │                 │                     │       │ SPI                      │
 │  STM32L071 (ou ESP32)  │                     │   RFM95W (SX1276) 868 MHz        │
 │      │ SPI             │                     │       │                          │
 │  RFM95W ── ANT 868 ────┼───────))) (((───────┼─── ANT 868 (déportée sur mât)    │
 │      │                 │                     │       │ I²C                      │
 │  LED verte / rouge     │                     │  4× MCP23017 (64 GPIO)           │
 │  Pile Li-SOCl₂ 3,6 V   │                     │       │                          │
 └────────────────────────┘                     │  Étage d'isolation optocouplée   │
                                                 │   ├─ 22 sorties X (carte → API)  │
   BOUTON 2 (station 2)                          │   └─ 21 entrées Y (API → carte)  │
 ┌────────────────────────┐                     │       │                          │
 │        idem            │────))) (((──────────┤  SUB-D 25 M / SUB-D 25 F         │
 └────────────────────────┘                     │       │                          │
                                                 │  Automate MEIDEN (CN61→CN64)     │
   BOUTON n … (extensible)                       └──────────────────────────────────┘
```

**Point clé** : l'ESP32 embarqué reprend **l'intégralité** du rôle de l'ATmega2560 d'origine (séquenceur temps réel des bus X/Y, file de courses, décodeur de position) **et** le rôle radio de l'ESP32 d'origine. Un seul microcontrôleur remplace les deux.

---

## 3. Fonctionnement détaillé

### 3.1 Couche radio

| Paramètre | Valeur retenue | Justification |
|---|---|---|
| Fréquence | 869,525 MHz (sous-bande g3) ou 868,1 MHz (g1) | g3 autorise 10 % de rapport cyclique et 500 mW ERP → marge confortable ; g1 limitée à 1 % / 25 mW |
| Modulation | LoRa (CSS) | Robustesse au bruit impulsionnel des variateurs / soudeuses |
| Spreading Factor | SF9 | Compromis portée / temps d'antenne. SF7 si portée < 150 m confirmée |
| Bande passante | 125 kHz | Standard |
| Coding Rate | 4/5 | Correction d'erreurs légère suffisante en portée courte |
| Puissance | +14 dBm (g1) / +20 dBm possible en g3 | À ajuster selon mesure de terrain |
| Sync word | `0x12` (privé) | Isole totalement du trafic LoRaWAN environnant (`0x34`) |
| Temps d'antenne (16 o, SF9/125k) | ≈ 100 ms | Base du calcul de rapport cyclique |
| Latence bouton → exécution | ≈ 200–250 ms (appel + accusé) | Aller ~100 ms + retournement + ACK ~100 ms |

**Contrainte de rapport cyclique (ERC 70-03 / EN 300 220)** : c'est le point de dimensionnement le plus souvent oublié :

- En g1 (1 %) avec 100 ms de ToA → **1 émission toutes les 10 s maximum par équipement**. Suffisant pour un bouton d'appel, tendu pour la télémétrie.
- Télémétrie AGV à 30 s de période → 100 ms / 30 s = **0,33 %** → conforme en g1.
- Si on veut de la télémétrie à 5 s, passer en g3 (10 %) est obligatoire.

### 3.2 Format de trame applicatif

Trame courte, à champs fixes, CRC applicatif en plus du CRC LoRa matériel :

```
Octet  0     : 0xA5              préambule applicatif (filtre les faux réveils)
Octet  1     : 0x01              version du protocole
Octet  2     : node_id_source    (0x01..0x7F = boutons, 0x80 = AGV)
Octet  3     : node_id_dest      (0xFF = broadcast)
Octet  4     : type_message      voir table ci-dessous
Octet  5     : seq               numéro de séquence 8 bits roulant
Octet  6..N  : payload
Octet N+1..2 : CRC16-CCITT sur les octets 0..N
```

| Type | Code | Payload | Sens |
|---|---|---|---|
| `CMD_GOTO` | 0x10 | station (u16) + vitesse (u8, 0-15) | Bouton → AGV |
| `CMD_STOP` | 0x11 | - | Bouton → AGV |
| `CMD_CLEAR` | 0x12 | : (vide la file de courses) | Bouton → AGV |
| `TELEMETRY` | 0x20 | station courante (u16), vitesse (u8), état (u8), nb courses en file (u8), Vbat (u8) | AGV → broadcast |
| `ACK` | 0x30 | seq acquitté (u8), code résultat (u8) | AGV → bouton |
| `NACK` | 0x31 | seq (u8), code erreur (u8) | AGV → bouton |

**Fiabilisation** :
- Chaque `CMD_*` est retransmise jusqu'à 3 fois si aucun `ACK` n'arrive dans 400 ms, avec back-off aléatoire de 50–150 ms (évite la collision de deux boutons pressés simultanément).
- Le numéro de séquence rend l'ordre **idempotent** : si l'AGV reçoit deux fois la même `seq` du même `node_id`, il ré-acquitte sans ré-exécuter. Indispensable, sinon un ACK perdu déclenche une course en double.
- Chiffrement optionnel AES-128-CTR (clé partagée en flash) sur le payload. Recommandé même en réseau privé : sans lui, n'importe qui avec un module à 10 € peut appeler l'AGV.

### 3.3 Interface avec l'automate MEIDEN (côté AGV)

C'est la partie la plus critique du redesign, et elle est **identique dans les trois architectures**.

| Bus | Sens | Largeur | Rôle |
|---|---|---|---|
| X | ESP32 → automate | 22 signaux | Commandes : adresse destination (10 bits, 1024 valeurs), vitesse (4 bits), bits de contrôle |
| Y | Automate → ESP32 | 21 signaux | États : position courante (Y23–Y34), accusés (Y05, Y10), défauts |

**Séquence d'écriture d'une destination** (reproduite à l'identique du firmware d'origine) :

1. Poser l'adresse destination sur les 10 lignes du bus X
2. Poser la vitesse sur les 4 lignes dédiées
3. Attendre le temps de stabilisation (t_setup, à mesurer à l'oscilloscope sur la carte d'origine)
4. Lever X82 (front de validation « start »)
5. Attendre Y05 (accusé automate) : timeout et compteur de tentatives (`Start tries`)
6. Retomber X82

La séquence d'arrêt est symétrique : X83 / Y10, avec son propre compteur.

**File de courses** : jusqu'à 5 destinations en attente. Sur la carte d'origine elle n'existe qu'en RAM du MEGA, elle est perdue à chaque coupure. **Amélioration à intégrer** : la stocker en NVS (flash ESP32), ce qui rend le système robuste au redémarrage. C'est un gain fonctionnel gratuit du redesign.

**Isolation électrique** : optocoupleurs sur les 43 lignes, dans les deux sens.
- Sorties X : MCP23017 → PC847 (LED) → phototransistor côté automate, avec résistance de tirage adaptée au rail de l'automate.
- Entrées Y : ligne automate → résistance de limitation → PC847 → MCP23017.
- ⚠️ **Point ouvert** : la valeur des résistances d'entrée dépend de l'amplitude réelle des lignes Y (rail LM7806 = 6 V ? ou 24 V ?). **À mesurer à l'oscilloscope sur Y05 en fonctionnement avant de figer le schéma.**

### 3.4 Boutons d'appel

Chaque bouton est un nœud autonome sur pile :

- Sommeil profond permanent (< 2 µA), réveil sur front du bouton (interruption GPIO)
- Émission de la trame `CMD_GOTO`, attente d'ACK jusqu'à 400 ms, jusqu'à 3 tentatives
- Retour visuel : LED verte fixe 2 s = ACK reçu ; LED rouge clignotante = pas d'accusé après 3 essais (l'opérateur sait immédiatement que l'appel n'est pas passé, fonction absente de la solution EnOcean pure)
- Consommation : ~120 mA pendant 100 ms d'émission. Avec une pile Li-SOCl₂ ER14505 (2,6 Ah), et 100 appels/jour, l'autonomie est dominée par l'autodécharge → **> 5 ans réalistes**, à valider par calcul de budget énergétique complet
- Ajout d'un bouton = flasher un `node_id` + une station. Aucune modification côté AGV.

---

## 4. Points forts

| | |
|---|---|
| **Homogénéité** | Une seule technologie radio, un seul jeu de compétences, une seule pièce de rechange (RFM95W) à stocker |
| **Latence bornée et faible** | ~200 ms, déterministe, sans dépendance à un tiers |
| **Aucun point de défaillance unique** | Chaque bouton parle directement à l'AGV. La panne d'un bouton n'affecte pas les autres |
| **Aucun coût récurrent** | Bande ISM libre, pas d'abonnement, pas de passerelle, pas de serveur |
| **Aucune dépendance externe** | Ni opérateur, ni cloud, ni réseau informatique de l'usine. Fonctionne même si l'IT tombe |
| **Immunité à la saturation 2,4 GHz** | Objectif initial du projet, pleinement atteint |
| **Portée très large** | Plusieurs centaines de mètres en intérieur industriel à SF9, bien au-delà du besoin. Marge de liaison confortable |
| **Accusé de réception natif** | L'opérateur sait si son appel est passé |
| **Extensibilité triviale** | +1 bouton = +1 nœud, sans reconfiguration du système |
| **Coût matériel faible** | ~35–45 € par bouton, ~90 € pour la carte AGV (hors PCB et main d'œuvre) |

---
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

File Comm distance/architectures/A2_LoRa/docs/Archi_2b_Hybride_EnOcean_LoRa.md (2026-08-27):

> Document de référence : projet « Remplacement de la carte AIO AGV Control V5.0.1 »
> AGV MEIDEN à guidage magnétique, appel depuis boutons déportés vers points d'arrêt.

# Architecture 3 : Hybride EnOcean + LoRa (architecture retenue)

**Statut : architecture validée en fin de conversation initiale, sous réserve que le « sans-pile » soit une exigence réelle du client.**

---

## 1. Fonction

Combiner l'avantage propre à chaque technologie plutôt que d'en imposer une seule :

- **EnOcean** sur le tronçon bouton → poste fixe : boutons **auto-alimentés par l'énergie de l'appui**, sans pile, sans maintenance, sans câblage.
- **LoRa 868 MHz** sur le tronçon poste fixe → AGV : liaison longue portée à latence bornée vers une cible mobile.
- Le **poste fixe** joue le rôle de traducteur de protocole entre les deux, et embarque au passage l'interface de supervision.

---
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

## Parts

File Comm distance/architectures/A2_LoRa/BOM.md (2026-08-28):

# Nomenclature A2 : LoRa 868 MHz

## 💰 Total

| | HT | TTC | *Accessoires écartés* |
|---|---:|---:|---:|
| **A2 : LoRa, poste central compris** | **345,15 €** | **414,18 €** | *+ 72,00 € HT* |

Ces totaux ne comptent que les **composants déterminants**.

Les accessoires arbitrables selon le budget : antennes, boîtiers,
coffrets, enveloppes murales, câbles : sont volontairement **hors
nomenclature** : ils se substituent librement d'un fournisseur à l'autre
et ne changent rien à la conception. La dernière colonne rappelle ce
qu'ils pèsent, pour que ce total ne soit jamais pris pour un coût
d'achat complet.

⚠️ [`../../docs/COMPARAISON.md`](../../docs/COMPARAISON.md) et le `README.md` racine comparent les architectures
**accessoires compris**, sans quoi le classement serait faussé. Leurs
chiffres sont donc plus élevés que ceux-ci, et c'est normal.

## ⚠️ Feuille de sourcing, à compléter avant usage

Ce document est une **liste d'achat à remplir**, pas un devis. Les colonnes
`Réf. catalogue`, `PU TTC` et `Total TTC` sont vides : c'est le service achats
qui les renseigne depuis le catalogue.

| Colonne | Ce qu'elle contient |
|---|---|
| `Réf. fabricant` | **Référence exacte à rechercher** : c'est ce qui rend la ligne non ambiguë |
| `Lien d'achat` | **Recherche pré-remplie chez le distributeur**, RS en premier chaque fois que c'est plausible. Un second lien n'apparaît que lorsque RS ne distribue probablement pas la référence |
| `Réf. catalogue` / `PU TTC` / `Total TTC` | **À remplir** |
| *`Repère TTC`* | Estimation de départ, **en italique** : voir l'avertissement ci-dessous |

### ⚠️ Ce sont des liens de RECHERCHE, pas des fiches produit

Chaque lien lance une **recherche sur la référence fabricant** chez le
distributeur. Aucun numéro de stock n'a été vérifié : le site de RS bloque
l'accès automatisé, il n'était donc pas possible de confirmer qu'une fiche
produit existe ni à quel prix. Inventer des numéros de stock aurait produit des
liens crédibles menant à la mauvaise pièce : le pire résultat possible sur une
liste d'achat.

C'est au service achats de retenir la bonne fiche et d'en reporter la référence
dans la colonne `Réf. catalogue`. Si une recherche RS ne donne rien, la ligne
suit un second lien vers Mouser, Digi-Key ou Amazon.

**RS est mis en tête partout**, y compris sur les références EnOcean et Unipi
qu'il ne distribue habituellement pas : le catalogue évolue, et une commande
groupée chez un fournisseur déjà référencé vaut souvent le surcoût unitaire.

### ⚠️ Les repères ne sont PAS des prix RS

Les repères viennent des nomenclatures d'étude, établies sur des prix de
composants génériques, puis converties en TTC (TVA 20 %). **Chez un
distributeur industriel comme RS, les mêmes références coûtent couramment 2 à
4 fois plus.** Un module ESP32 y est plutôt à 15–25 € qu'à 6 €.

Ces repères servent à deux choses, et à rien d'autre :

- vérifier qu'une ligne relevée au catalogue n'est pas aberrante (erreur de
  référence, conditionnement par 100, prix pour un lot) ;
- garder un ordre de grandeur tant que la feuille n'est pas remplie.

**Le total d'une feuille complétée sera nettement supérieur au total des
repères.** C'est normal, et c'est le prix de la traçabilité d'un distributeur
référencé : disponibilité, garantie, facture, fiches techniques.

### Note pour l'arbitrage

Les prix sont demandés en TTC. Pour une entreprise, **la TVA est récupérable** :
la comparaison entre architectures reste donc pertinente en HT, et
[`../../docs/COMPARAISON.md`](../../docs/COMPARAISON.md) raisonne en HT. Diviser un total TTC par 1,20 donne le HT.

---

### Carte AGV `AIO_AGV_Control_V6.0`

**Nomenclature réelle**, extraite de
[`../../materiel/AIO_AGV_Control_V6.0/`](../../materiel/AIO_AGV_Control_V6.0/) :
58 composants placés au PCB.

C'est la **V5.0.1 au composant près, plus un `RFM95W-868S2`** : le
diff des deux projets KiCad ne montre aucun autre écart. La radio est
**intégrée à la carte**, câblée sur le SPI libre de l'ESP32 : il n'y a
ni carte fille ni câblage volant.

⚠️ Cette carte est **fabriquée**. La V5.0.1 d'origine reste intacte sur
le chariot : c'est le retour arrière de cette architecture.

| Désignation | Réf. fabricant | Qté | Lien d'achat | Réf. catalogue | PU TTC | Total TTC | *Repère TTC* |
|---|---|---:|---|---|---:|---:|---:|
| Module MCU : carte Mega2560 Pro sur support | `Clone Mega2560 Pro (A1)` | 1 | [RS](https://fr.rs-online.com/web/c/?searchTerm=Clone+Mega2560+Pro) · [Amazon](https://www.amazon.fr/s?k=Clone+Mega2560+Pro) | ☐ | ☐ | ☐ | *21,60 €* |
| Module Wi-Fi/BT sur support | `ESP32-DEVKITC-32D-F (U1)` | 1 | [RS](https://fr.rs-online.com/web/c/?searchTerm=ESP32-DEVKITC-32D-F) | ☐ | ☐ | ☐ | *14,40 €* |
| **Étage de sortie** : MOSFET N canal TO-220 | `IRF520 (Vishay, T1–T24)` | 23 | [RS](https://fr.rs-online.com/web/c/?searchTerm=IRF520) | ☐ | ☐ | ☐ | *16,56 €* |
| Résistances de grille des MOSFET | `1 kΩ THT 0411 (R1–R24)` | 23 | [RS](https://fr.rs-online.com/web/c/?searchTerm=1+k%CE%A9+THT+0411) | ☐ | ☐ | ☐ | *1,38 €* |
| Diviseurs de mesure | `4,7 k / 2,2 k / 22 k / 220 k (R30, R31, R40, R41)` | 4 | [RS](https://fr.rs-online.com/web/c/?searchTerm=4%2C7+k+%2F+2%2C2+k+%2F+22+k+%2F+220+k) | ☐ | ☐ | ☐ | *0,24 €* |
| Régulateur 6 V : alimentation de l'ATmega | `L7806CV (LM1)` | 1 | [RS](https://fr.rs-online.com/web/c/?searchTerm=L7806CV) | ☐ | ☐ | ☐ | *1,08 €* |
| Convertisseur DC/DC **isolé** 24 V → 5 V, 5 W | `TDN 5-2411WISM (Traco, TDN1)` | 1 | [RS](https://fr.rs-online.com/web/c/?searchTerm=TDN+5-2411WISM) | ☐ | ☐ | ☐ | *30,00 €* |
| Diode de protection DO-41 | `1N4007 ou équiv. (D1)` | 1 | [RS](https://fr.rs-online.com/web/c/?searchTerm=1N4007) | ☐ | ☐ | ☐ | *0,12 €* |
| Connecteur SUB-D 25 **mâle** coudé CI (entrées) | `Amphenol DB25P564CTXLF (J1)` | 1 | [RS](https://fr.rs-online.com/web/c/?searchTerm=Amphenol+DB25P564CTXLF) | ☐ | ☐ | ☐ | *7,20 €* |
| Connecteur SUB-D 25 **femelle** coudé CI (sorties) | `Amphenol DB25S564GTLF (J2)` | 1 | [RS](https://fr.rs-online.com/web/c/?searchTerm=Amphenol+DB25S564GTLF) | ☐ | ☐ | ☐ | *7,20 €* |
| Supports et barrettes pour les deux modules | `barrettes tulipe 2,54 mm` | 1 | [RS](https://fr.rs-online.com/web/c/?searchTerm=barrettes+tulipe+2%2C54+mm) | ☐ | ☐ | ☐ | *3,60 €* |
| PCB ~150 × 100 mm (série de 5) | `Gerber projet` | 1 | [JLCPCB](https://jlcpcb.com/quote) · [PCBWay](https://www.pcbway.com/orderonline.aspx) | ☐ | ☐ | ☐ | *18,00 €* |
| **Module LoRa SX1276 868 MHz** : l'unique écart avec la V5.0.1 | `RFM95W-868S2 (HopeRF, U2)` | 1 | [RS](https://fr.rs-online.com/web/c/?searchTerm=RFM95W-868S2) · [Amazon](https://www.amazon.fr/s?k=RFM95W-868S2) | ☐ | ☐ | ☐ | *12,00 €* |
| **Sous-total** | | | | | | **☐** | ***133,38 €*** |

### **[A2]** Poste central : UniPi Lite 1.1

Le poste reçoit les appels **en LoRa** depuis les boutons sur pile, et
renvoie les missions **en LoRa** vers la carte AGV. Une seule radio suffit :
le SX1276 est half-duplex, et `LoraTransport` ordonnance déjà les deux sens.

⚠️ Nouveau depuis le 2026-08-28. A3 se définissait auparavant par l'absence
de poste : voir [`../../docs/ARCHITECTURE_COMMUNE.md`](../../../docs/ARCHITECTURE_COMMUNE.md).

| Désignation | Réf. fabricant | Qté | Lien d'achat | Réf. catalogue | PU TTC | Total TTC | *Repère TTC* |
|---|---|---:|---|---|---:|---:|---:|
| Poste central Linux : hébergement de l'API de planning | `UniPi 1.1 Lite + Raspberry Pi 4` | 1 | [RS](https://fr.rs-online.com/web/c/?searchTerm=UniPi+1.1+Lite+%2B+Raspberry+Pi+4) | ☐ | ☐ | ☐ | *156,00 €* |
| Carte microSD 16 Go qualité industrielle | `SanDisk Industrial ou équiv.` | 1 | [RS](https://fr.rs-online.com/web/c/?searchTerm=SanDisk+Industrial) | ☐ | ☐ | ☐ | *14,40 €* |
| Alimentation rail DIN 230 V vers 24 V 15 W | `MEAN WELL HDR-15-24` | 1 | [RS](https://fr.rs-online.com/web/c/?searchTerm=MEAN+WELL+HDR-15-24) | ☐ | ☐ | ☐ | *16,80 €* |
| Module LoRa SX1276 868 MHz sur le SPI du Raspberry Pi | `RFM95W-868S2 (HopeRF)` | 1 | [RS](https://fr.rs-online.com/web/c/?searchTerm=RFM95W-868S2) · [Amazon](https://www.amazon.fr/s?k=RFM95W-868S2) | ☐ | ☐ | ☐ | *12,00 €* |
| Carte fille : RFM95W vers le connecteur 40 broches | `PCB 2 couches + barrettes` | 1 | [JLCPCB](https://jlcpcb.com/quote) · [PCBWay](https://www.pcbway.com/orderonline.aspx) | ☐ | ☐ | ☐ | *9,60 €* |
| **Sous-total** | | | | | | **☐** | ***208,80 €*** |

### Outillage : non récurrent

| Désignation | Réf. fabricant | Qté | Lien d'achat | Réf. catalogue | PU TTC | Total TTC | *Repère TTC* |
|---|---|---:|---|---|---:|---:|---:|
| Dongle RTL-SDR + antenne : occupation de la bande 868 MHz | `RTL-SDR Blog V4` | 1 | [RS](https://fr.rs-online.com/web/c/?searchTerm=RTL-SDR+Blog+V4) · [Amazon](https://www.amazon.fr/s?k=RTL-SDR+Blog+V4) | ☐ | ☐ | ☐ | *36,00 €* |
| Analyseur logique 8 voies : chronogrammes X/Y | `clone Saleae 24 MHz` | 1 | [RS](https://fr.rs-online.com/web/c/?searchTerm=clone+Saleae+24+MHz) · [Amazon](https://www.amazon.fr/s?k=clone+Saleae+24+MHz) | ☐ | ☐ | ☐ | *18,00 €* |
| Adaptateur USB-série 3,3 V | `FTDI FT232RL ou CP2102` | 1 | [RS](https://fr.rs-online.com/web/c/?searchTerm=FTDI+FT232RL+ou+CP2102) · [Amazon](https://www.amazon.fr/s?k=FTDI+FT232RL+ou+CP2102) | ☐ | ☐ | ☐ | *7,20 €* |
| Mesure de courant µA : sommeil profond **[A2]** | `multimètre à faible burden voltage` | 1 | [RS](https://fr.rs-online.com/web/c/?searchTerm=multim%C3%A8tre+%C3%A0+faible+burden+voltage) · [Amazon](https://www.amazon.fr/s?k=multim%C3%A8tre+%C3%A0+faible+burden+voltage) | ☐ | ☐ | ☐ | *10,80 €* |
| **Sous-total** | | | | | | **☐** | ***72,00 €*** |

---

## Récapitulatif

| Poste | Total TTC relevé | *Repère TTC* | *Repère HT* |
|---|---:|---:|---:|
| Carte AGV `V6.0` (nomenclature KiCad) | ☐ | *133,38 €* | *111,15 €* |
| Poste central UniPi Lite 1.1 | ☐ | *208,80 €* | *174,00 €* |
| Outillage | ☐ | *72,00 €* | *60,00 €* |
| **TOTAL** | **☐** | ***414,18 €*** | ***345,15 €*** |

⚠️ La version **EU 868 MHz** du `PTM 210` est impérative : les déclinaisons
902 et 928 MHz ne sont pas utilisables en France, et rien dans la désignation
courante ne les distingue au premier coup d'œil.

### La V6.0, c'est la V5.0.1 plus une radio

Le diff des deux projets KiCad est sans ambiguïté : **58 empreintes contre 57,
un seul écart, le `RFM95W-868S2`.** Tout le reste : `Mega2560 Pro`,
`ESP32-DEVKITC`, les 23 `IRF520` et leurs résistances de grille, le `L7806CV`,
le `TDN 5-2411WISM`, les deux SUB-D 25 : est strictement identique.

La radio est **intégrée à la carte**, câblée sur le SPI que l'ESP32 laissait
libre. Le relevé confirme le brochage :

| RFM95W | ESP32 |
|---|---|
| `NSS` | `IO5` |
| `SCK` | `IO18` |
| `MISO` | `IO19` |
| `MOSI` | `IO23` |
| `DIO0` | `IO26` |

⚠️ **`RESET` n'est pas câblée.** Un module figé ne se récupérera qu'en coupant
l'alimentation de la carte : aucun reset logiciel n'est possible. Une GPIO libre
suffirait à corriger cela sur une V6.1 : il en reste largement.

⚠️ **`IO16` et `IO17` sont interdites** : elles portent la liaison série vers le
`Mega2560 Pro`.

### Ce que cela change par rapport aux versions précédentes de ce document

Les nomenclatures antérieures chiffraient la carte LoRa comme une **V5.0.1
réutilisée** à 0 €, augmentée d'une carte fille portant le `RFM95W`. C'était une
hypothèse de travail ; la V6.0 la remplace, et **elle est plus chère** :

| | Hypothèse précédente | **V6.0 réelle** |
|---|---:|---:|
| Carte AGV | 18,00 € HT *(greffe)* | **111,15 € HT** *(fabriquée)* |

La carte est à produire, comme celle de l'architecture A3. En contrepartie il
n'y a **ni carte fille, ni câblage volant dans un chariot qui vibre** : ce qui,
sur un équipement destiné à durer, vaut largement l'écart.

La V5.0.1 d'origine **reste intacte sur le chariot** : c'est le retour arrière
de cette architecture.

### La liaison entre les deux microcontrôleurs n'est pas un UART

Le relevé KiCad corrige une hypothèse qui était fausse, et le firmware a été
corrigé en conséquence.

```
MEGA D53 (PB0) ──[2,2 k]──┬── ESP32 IO16 (U2RXD)     5 V ramenés à 3,4 V
                          │
                       [4,7 k]
                          │
                         GND

ESP32 IO17 (U2TXD) ───────── MEGA D52 (PB1)          3,3 V lus en logique 5 V
```

Côté ESP32 c'est bien `UART2`. **Côté MEGA, D52 et D53 ne sont pas des broches
d'UART matériel**, et les trois UART du MEGA sont inutilisables, car leurs
broches de réception portent des signaux du bus : `D19`/`PD2` = `Y13`,
`D17`/`PH0` = `Y11`, `D15`/`PJ0` = **`Y05`**, le drapeau de déplacement.

Un `Serial1.begin()` aurait mis `Y13` en sortie **contre la sortie de
l'automate**. Le firmware passe donc en `SoftwareSerial` sur D52/D53, à
**38 400 bauds** : 115 200 n'est pas tenable en émulation logicielle sur AVR.

### Pourquoi pas un Unipi Gate pour ce poste ?

Le poste doit désormais héberger l'API de planning : il lui faut Linux, un
système de fichiers et une horloge. La question devient donc **quel** Linux.

**Pas un Unipi Gate G100, et pour une raison de fond.** C'est un boîtier DIN
fermé : Ethernet, RS485, un port USB. **Aucun connecteur SPI, aucun GPIO,
aucune embase d'antenne.** Or le `RFM95W` est un composant SPI qu'il faut
piloter au niveau du PHY.

Les contournements coûtent tous plus cher que le montage retenu :

| Contournement | Coût | Ce qu'on y perd |
|---|---:|---|
| Dongle LoRa USB | ~30,00 € + hub | L'unique port USB sert déjà si des boutons EnOcean sont installés |
| Modem LoRa UART/RS485 (`E32-868T20D`, `RAK3172`) | ~18,00 € | **Le module gère le PHY lui-même** : il faudrait réécrire `LoraTransport`, et surtout **abandonner le contrôle du budget de rapport cyclique** que le firmware applique et teste aujourd'hui. C'est une obligation réglementaire, pas un réglage |

L'**UniPi Lite 1.1** est un Raspberry Pi avec sa carte d'extension : le SPI y
est libre, les GPIO aussi, et
[`../../bancs/lora/linux/`](../../bancs/lora/linux/) pilote déjà ce montage avec
la trame du projet.

### Coûts récurrents

| Poste | Annuel |
|---|---:|
| Abonnement opérateur | **0 €** : bande ISM libre |
| Infrastructure | **0 €** : aucune |
| **[A2]** Remplacement des piles | ~7,20 € par bouton tous les 5 à 8 ans |
| **[A2]** Piles | **0 €** : PTM 210 auto-alimentés |

**C'est l'architecture la moins chère des trois sur dix ans.**

---

## Risques d'approvisionnement et délais

| Élément | Délai typique | Risque |
|---|---|---|
| PCB 4 couches + assemblage | 3 à 5 semaines | **Chemin critique matériel** |
| **[A2]** PCB bouton + boîtiers IP65 | 3 à 5 semaines | En parallèle de la carte AGV |
| `RFM95W-868S2` | 1 à 3 semaines | **Contrefaçons fréquentes** : acheter chez un distributeur référencé, pas sur une place de marché |
| `PTM 210` / `TCM 515` | 1 à 2 semaines | Peu distribués par RS : prévoir un distributeur EnOcean |
| `ER14505` Li-SOCl₂ | 1 à 2 semaines | **Restrictions de transport aérien** sur le lithium |
| `ESP32-DEVKITC`, `Mega2560 Pro`, `IRF520` | stock | Faible |

**Ne rien commander avant la phase 1 de [`DEPLOY.md`](DEPLOY.md)** : le relevé de
couverture radio et l'arbitrage du facteur d'étalement peuvent changer
l'antenne, la puissance d'émission et le nombre de nœuds.

## Ce que cette nomenclature ne couvre pas

- **La main-d'œuvre** : 5 à 8 jours-homme après la phase 0 qui rend ce dossier
  autonome, hors développement.
- **La conformité RED** : si les cartes sont produites en série et mises sur le
  marché, dossier technique, marquage CE et déclaration UE de conformité à
  conserver 10 ans. Compter 3 à 5 jours-homme. Sans objet en usage interne.
- **La carte de rechange** : ~73,44 € pour un échange standard. Recommandé.
- **Un éventuel relais LoRa** si le relevé révèle une zone morte : ~48,00 €,
  mais surtout une complexité applicative hors périmètre actuel.
---

## Analyse critique de cette nomenclature

### ✅ Corrigé : le convertisseur du bouton était inutile

La nomenclature d'étude prévoyait un `TPS62740` (buck ultra-basse consommation)
entre la pile et l'électronique. Il n'a pas lieu d'être : une pile Li-SOCl₂
délivre **3,6 V**, et les deux consommateurs l'acceptent directement :
`STM32L071` de 1,65 à 3,6 V, `RFM95W` de 1,8 à 3,7 V. Le convertisseur ajoutait
un composant, un courant de repos et un mode de panne, pour rien.

Le vrai besoin est ailleurs : une cellule Li-SOCl₂ a une **impédance interne
élevée**, et l'émission LoRa tire ~120 mA pendant quelques centaines de
millisecondes. Sans réservoir, la tension s'effondre et le microcontrôleur
redémarre : panne classique, et intermittente, donc pénible à diagnostiquer.

`TPS62740` remplacé par **220 µF tantale + 10 µF X7R** : 1,68 € d'économie, un
composant de moins, et le problème réellement traité.

Une diode Schottky est ajoutée en protection de la pile (0,24 €) contre une
inversion au remplacement.

### ⚠️ L'`IRF520` n'est pas un MOSFET « logic-level »

La V6.0 hérite de l'étage de sortie de la V5.0.1 : **23 `IRF520`**, dont la
tension de seuil est spécifiée de 2 à 4 V et le `Rds(on)` garanti à Vgs = 10 V.
Attaqué par une broche à 5 V, il conduit, mais hors des conditions du
constructeur.

Pour quelques milliampères sur une entrée d'automate, cela fonctionne. Ce n'est
pas un défaut bloquant, c'est un choix hors spécification qu'il faut connaître
avant de l'attribuer à autre chose le jour où une voie se comporte mal en
température. L'`IRL520` est la version logic-level du même composant, **au même
brochage** : une substitution sans reroutage.

### ⚠️ À vérifier : l'autonomie annoncée

5 à 8 ans sur une `ER14505` de 2,6 Ah suppose un sommeil profond sous 2 µA et
quelques appuis par jour. **À mesurer au banc** (phase 7 de `DEPLOY.md`) : un
courant de repos de 20 µA au lieu de 2 divise l'autonomie par cinq, et
transforme une maintenance décennale en corvée annuelle.

### ✅ Confirmé : les 43 lignes sur les broches de l'ATmega

La V6.0 reprend la topologie de la V5.0.1 : le `Mega2560 Pro` porte les 43
lignes sur ses propres broches, sans expandeur ni registre à décalage. Le
relevé de câblage montre que les 22 sorties occupent 5 ports, soit **5
écritures ≈ 0,3 µs** en section critique : 500 fois plus rapide qu'un expandeur
I²C.

Le driver `avr_port_bus.cpp` est déjà écrit et testé, et le relevé complet vit
dans `firmware/mega/src/board_ports.h`. Il n'y a rien à concevoir de ce côté.

---

## Mode d'emploi pour le service achats

1. Rechercher chaque `Réf. fabricant` sur [fr.rs-online.com](https://fr.rs-online.com).
2. Renseigner la référence RS (numéro de stock), le prix unitaire TTC et le total.
3. Si la référence est absente du catalogue RS : chercher sur Amazon, et
   **noter la source dans la colonne `Réf. catalogue`** : la traçabilité de
   l'origine compte autant que le prix.
4. Attention aux **conditionnements** : un IRF520 ou une résistance se vend
   souvent par 5, 10 ou 100. Le prix unitaire affiché peut correspondre à un
   lot entier.
5. Les lignes marquées `PCB` ne sont pas des articles de catalogue : elles
   demandent un devis chez un fabricant de circuits imprimés
   (JLCPCB, Eurocircuits, PCBWay) à partir des fichiers Gerber.
6. Reporter les sous-totaux dans le récapitulatif, puis **mettre à jour
   [`../../docs/COMPARAISON.md`](../../docs/COMPARAISON.md)** si les écarts changent le classement des architectures.

## Équivalences acceptables

Ces substitutions ne changent rien au fonctionnement, et peuvent débloquer une
rupture de stock :

| Référence | Équivalents |
|---|---|
| `IRF520` | `IRL520N` : version **logic-level**, brochage identique |
| `RFM95W-868S2` | Tout module SX1276 868 MHz au même brochage |
| `TSR 1-2450` | `OKI-78SR-5/1.5-W36-C` (Murata), même brochage |
| `AP2112K-3.3TRG1` | `MCP1700T-3302E`, `XC6206P332MR` |
| `ER14505` | `LS14500` (Saft), `SL-360` (Tadiran) : Li-SOCl₂ 3,6 V AA |
| `TCM 515` | `TCM 310` si l'accusé opérateur n'est pas retenu |

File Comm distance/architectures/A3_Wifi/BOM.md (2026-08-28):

# Nomenclature A3 : Wi-Fi + EnOcean (carte V5.0.1 conservée)

## 💰 Total

| | HT | TTC | *Accessoires écartés* |
|---|---:|---:|---:|
| **A3 : Wi-Fi + EnOcean** | **490,65 €** | **588,78 €** | *+ 101,50 € HT* |

Ces totaux ne comptent que les **composants déterminants**.

Les accessoires arbitrables selon le budget : antennes, boîtiers,
coffrets, enveloppes murales, câbles : sont volontairement **hors
nomenclature** : ils se substituent librement d'un fournisseur à l'autre
et ne changent rien à la conception. La dernière colonne rappelle ce
qu'ils pèsent, pour que ce total ne soit jamais pris pour un coût
d'achat complet.

⚠️ [`../../docs/COMPARAISON.md`](../../docs/COMPARAISON.md) et le `README.md` racine comparent les architectures
**accessoires compris**, sans quoi le classement serait faussé. Leurs
chiffres sont donc plus élevés que ceux-ci, et c'est normal.

## ⚠️ Feuille de sourcing, à compléter avant usage

Ce document est une **liste d'achat à remplir**, pas un devis. Les colonnes
`Réf. catalogue`, `PU TTC` et `Total TTC` sont vides : c'est le service achats
qui les renseigne depuis le catalogue.

| Colonne | Ce qu'elle contient |
|---|---|
| `Réf. fabricant` | **Référence exacte à rechercher** : c'est ce qui rend la ligne non ambiguë |
| `Lien d'achat` | **Recherche pré-remplie chez le distributeur**, RS en premier chaque fois que c'est plausible. Un second lien n'apparaît que lorsque RS ne distribue probablement pas la référence |
| `Réf. catalogue` / `PU TTC` / `Total TTC` | **À remplir** |
| *`Repère TTC`* | Estimation de départ, **en italique** : voir l'avertissement ci-dessous |

### ⚠️ Ce sont des liens de RECHERCHE, pas des fiches produit

Chaque lien lance une **recherche sur la référence fabricant** chez le
distributeur. Aucun numéro de stock n'a été vérifié : le site de RS bloque
l'accès automatisé, il n'était donc pas possible de confirmer qu'une fiche
produit existe ni à quel prix. Inventer des numéros de stock aurait produit des
liens crédibles menant à la mauvaise pièce : le pire résultat possible sur une
liste d'achat.

C'est au service achats de retenir la bonne fiche et d'en reporter la référence
dans la colonne `Réf. catalogue`. Si une recherche RS ne donne rien, la ligne
suit un second lien vers Mouser, Digi-Key ou Amazon.

**RS est mis en tête partout**, y compris sur les références EnOcean et Unipi
qu'il ne distribue habituellement pas : le catalogue évolue, et une commande
groupée chez un fournisseur déjà référencé vaut souvent le surcoût unitaire.

### ⚠️ Les repères ne sont PAS des prix RS

Les repères viennent des nomenclatures d'étude, établies sur des prix de
composants génériques, puis converties en TTC (TVA 20 %). **Chez un
distributeur industriel comme RS, les mêmes références coûtent couramment 2 à
4 fois plus.** Un module ESP32 y est plutôt à 15–25 € qu'à 6 €.

Ces repères servent à deux choses, et à rien d'autre :

- vérifier qu'une ligne relevée au catalogue n'est pas aberrante (erreur de
  référence, conditionnement par 100, prix pour un lot) ;
- garder un ordre de grandeur tant que la feuille n'est pas remplie.

**Le total d'une feuille complétée sera nettement supérieur au total des
repères.** C'est normal, et c'est le prix de la traçabilité d'un distributeur
référencé : disponibilité, garantie, facture, fiches techniques.

### Note pour l'arbitrage

Les prix sont demandés en TTC. Pour une entreprise, **la TVA est récupérable** :
la comparaison entre architectures reste donc pertinente en HT, et
[`../../docs/COMPARAISON.md`](../../docs/COMPARAISON.md) raisonne en HT. Diviser un total TTC par 1,20 donne le HT.

---

### **[A2]** Carte AGV : extraite du projet KiCad

**Nomenclature réelle**, extraite de
[`../../materiel/AIO_AGV_Control_V5.0.1/`](../../materiel/AIO_AGV_Control_V5.0.1/) :
57 composants placés au PCB. Ce n'est plus une estimation d'étude.

⚠️ Cette carte est **fabriquée**, pas réutilisée : elle reprend le couple
ATmega2560 + ESP32 de l'originale, sur supports, avec son propre étage de
sortie. La ligne « carte AGV à 0 € » des versions précédentes de ce
document était donc fausse.

| Désignation | Réf. fabricant | Qté | Lien d'achat | Réf. catalogue | PU TTC | Total TTC | *Repère TTC* |
|---|---|---:|---|---|---:|---:|---:|
| Module MCU : carte Mega2560 Pro sur support | `Clone Mega2560 Pro (A1)` | 1 | [RS](https://fr.rs-online.com/web/c/?searchTerm=Clone+Mega2560+Pro) · [Amazon](https://www.amazon.fr/s?k=Clone+Mega2560+Pro) | ☐ | ☐ | ☐ | *21,60 €* |
| Module Wi-Fi/BT sur support | `ESP32-DEVKITC-32D-F (U1)` | 1 | [RS](https://fr.rs-online.com/web/c/?searchTerm=ESP32-DEVKITC-32D-F) | ☐ | ☐ | ☐ | *14,40 €* |
| **Étage de sortie** : MOSFET N canal TO-220 | `IRF520 (Vishay, T1–T24)` | 23 | [RS](https://fr.rs-online.com/web/c/?searchTerm=IRF520) | ☐ | ☐ | ☐ | *16,56 €* |
| Résistances de grille des MOSFET | `1 kΩ THT 0411 (R1–R24)` | 23 | [RS](https://fr.rs-online.com/web/c/?searchTerm=1+k%CE%A9+THT+0411) | ☐ | ☐ | ☐ | *1,38 €* |
| Diviseurs de mesure | `4,7 k / 2,2 k / 22 k / 220 k (R30, R31, R40, R41)` | 4 | [RS](https://fr.rs-online.com/web/c/?searchTerm=4%2C7+k+%2F+2%2C2+k+%2F+22+k+%2F+220+k) | ☐ | ☐ | ☐ | *0,24 €* |
| Régulateur 6 V : alimentation de l'ATmega | `L7806CV (LM1)` | 1 | [RS](https://fr.rs-online.com/web/c/?searchTerm=L7806CV) | ☐ | ☐ | ☐ | *1,08 €* |
| Convertisseur DC/DC **isolé** 24 V → 5 V, 5 W | `TDN 5-2411WISM (Traco, TDN1)` | 1 | [RS](https://fr.rs-online.com/web/c/?searchTerm=TDN+5-2411WISM) | ☐ | ☐ | ☐ | *30,00 €* |
| Diode de protection DO-41 | `1N4007 ou équiv. (D1)` | 1 | [RS](https://fr.rs-online.com/web/c/?searchTerm=1N4007) | ☐ | ☐ | ☐ | *0,12 €* |
| Connecteur SUB-D 25 **mâle** coudé CI (entrées) | `Amphenol DB25P564CTXLF (J1)` | 1 | [RS](https://fr.rs-online.com/web/c/?searchTerm=Amphenol+DB25P564CTXLF) | ☐ | ☐ | ☐ | *7,20 €* |
| Connecteur SUB-D 25 **femelle** coudé CI (sorties) | `Amphenol DB25S564GTLF (J2)` | 1 | [RS](https://fr.rs-online.com/web/c/?searchTerm=Amphenol+DB25S564GTLF) | ☐ | ☐ | ☐ | *7,20 €* |
| Supports et barrettes pour les deux modules | `barrettes tulipe 2,54 mm` | 1 | [RS](https://fr.rs-online.com/web/c/?searchTerm=barrettes+tulipe+2%2C54+mm) | ☐ | ☐ | ☐ | *3,60 €* |
| PCB ~150 × 100 mm (série de 5) | `Gerber projet` | 1 | [JLCPCB](https://jlcpcb.com/quote) · [PCBWay](https://www.pcbway.com/orderonline.aspx) | ☐ | ☐ | ☐ | *18,00 €* |
| **Sous-total** | | | | | | **☐** | ***121,38 €*** |

### **[A2]** Harnais de raccordement

La carte existe, mais son câblage vers l'automate est à refaire.
Détail : [`docs/subd25_atmega.md`](docs/subd25_atmega.md).

| Désignation | Réf. fabricant | Qté | Lien d'achat | Réf. catalogue | PU TTC | Total TTC | *Repère TTC* |
|---|---|---:|---|---|---:|---:|---:|
| Nappe 25 conducteurs, gaine souple, ~1 m | `3M 3365/25 ou équiv.` | 2 | [RS](https://fr.rs-online.com/web/c/?searchTerm=3M+3365%2F25) | ☐ | ☐ | ☐ | *14,40 €* |
| Connecteur IDC SUB-D 25 **mâle** (entrées) | `Amphenol L17D25P` | 1 | [RS](https://fr.rs-online.com/web/c/?searchTerm=Amphenol+L17D25P) | ☐ | ☐ | ☐ | *4,80 €* |
| Connecteur IDC SUB-D 25 **femelle** (sorties) | `Amphenol L17D25S` | 1 | [RS](https://fr.rs-online.com/web/c/?searchTerm=Amphenol+L17D25S) | ☐ | ☐ | ☐ | *4,80 €* |
| Capot métallisé SUB-D 25 avec serre-câble | `Amphenol 17E-1726-2` | 2 | [RS](https://fr.rs-online.com/web/c/?searchTerm=Amphenol+17E-1726-2) | ☐ | ☐ | ☐ | *8,40 €* |
| Cosses à sertir côté AGV (CN61 à CN64) | `selon bornier automate` | 50 | [RS](https://fr.rs-online.com/web/c/?searchTerm=selon+bornier+automate) | ☐ | ☐ | ☐ | *9,00 €* |
| **Sous-total** | | | | | | **☐** | ***41,40 €*** |

### **[A2]** Poste fixe : Unipi Gate G100

Le poste porte le récepteur EnOcean, le broker MQTT et l'interface de
supervision. **Le Gate G100 remplace l'E413 initialement prévu** : voir
la justification en fin de document.

| Désignation | Réf. fabricant | Qté | Lien d'achat | Réf. catalogue | PU TTC | Total TTC | *Repère TTC* |
|---|---|---:|---|---|---:|---:|---:|
| Passerelle Linux DIN : Debian, 16 Go eMMC, 2× Ethernet, USB 3.0, RS485 | `Unipi Gate G100` | 1 | [RS](https://fr.rs-online.com/web/c/?searchTerm=Unipi+Gate+G100) · [Unipi](https://www.unipi.technology/search?query=Unipi+Gate+G100) | ☐ | ☐ | ☐ | *240,00 €* |
| Récepteur EnOcean 868 MHz, UART ESP3 | `TCM 515 (EnOcean)` | 1 | [RS](https://fr.rs-online.com/web/c/?searchTerm=TCM+515) · [Mouser](https://www.mouser.fr/c/?q=TCM+515) · [Digi-Key](https://www.digikey.fr/fr/products/result?keywords=TCM+515) | ☐ | ☐ | ☐ | *33,60 €* |
| Adaptateur USB-série vers le TCM 515 | `FTDI FT232RL` | 1 | [RS](https://fr.rs-online.com/web/c/?searchTerm=FTDI+FT232RL) | ☐ | ☐ | ☐ | *9,60 €* |
| Alimentation rail DIN 230 V → 24 V 15 W | `MEAN WELL HDR-15-24` | 1 | [RS](https://fr.rs-online.com/web/c/?searchTerm=MEAN+WELL+HDR-15-24) | ☐ | ☐ | ☐ | *16,80 €* |
| **Sous-total** | | | | | | **☐** | ***300,00 €*** |

### Outillage : non récurrent

| Désignation | Réf. fabricant | Qté | Lien d'achat | Réf. catalogue | PU TTC | Total TTC | *Repère TTC* |
|---|---|---:|---|---|---:|---:|---:|
| Programmateur ISP : **sauvegarde puis flash de l'ATmega** | `USBasp ou USBtinyISP` | 1 | [RS](https://fr.rs-online.com/web/c/?searchTerm=USBasp+ou+USBtinyISP) · [Amazon](https://www.amazon.fr/s?k=USBasp+ou+USBtinyISP) | ☐ | ☐ | ☐ | *9,60 €* |
| Adaptateur USB-série 3,3 V : ESP32 et liaison inter-MCU | `FTDI FT232RL ou CP2102` | 1 | [RS](https://fr.rs-online.com/web/c/?searchTerm=FTDI+FT232RL+ou+CP2102) · [Amazon](https://www.amazon.fr/s?k=FTDI+FT232RL+ou+CP2102) | ☐ | ☐ | ☐ | *7,20 €* |
| Analyseur logique 8 voies : chronogrammes X/Y | `clone Saleae 24 MHz` | 1 | [RS](https://fr.rs-online.com/web/c/?searchTerm=clone+Saleae+24+MHz) · [Amazon](https://www.amazon.fr/s?k=clone+Saleae+24+MHz) | ☐ | ☐ | ☐ | *18,00 €* |
| Jeu de cosses + pince à sertir : confection du harnais | `Knipex ou Engineer PA-09` | 1 | [RS](https://fr.rs-online.com/web/c/?searchTerm=Knipex+ou+Engineer+PA-09) | ☐ | ☐ | ☐ | *54,00 €* |
| Kit réseau : testeur RJ45, sertisseuse | `lot` | 1 | - | ☐ | ☐ | ☐ | *37,20 €* |
| **Sous-total** | | | | | | **☐** | ***126,00 €*** |

---

## Ce que la nomenclature KiCad apprend

L'extraction du projet KiCad ne fait pas que donner des prix : elle renseigne
deux points qui étaient ouverts.

### 1. L'étage de sortie est à MOSFET : `x_open_drain` doit être `false`

Les 22 voies X passent par **23 IRF520** (MOSFET N canal, TO-220) attaqués par
des résistances de grille de 1 kΩ. C'est un étage à **collecteur ouvert
matériel** : le MOSFET tire la ligne de l'automate à la masse, il ne sort jamais
de niveau haut.

Conséquence directe sur le firmware : le microcontrôleur pilote une **grille**,
pas la ligne de l'automate. Il doit donc être en **sortie poussée**
(`bus.x_open_drain: false`). Le mode collecteur ouvert côté microcontrôleur
laisserait la grille **flottante** à l'état actif : un MOSFET à grille flottante
peut conduire partiellement, ce qui est le pire état possible sur un étage de
puissance.

L'inversion est faite par le MOSFET : microcontrôleur à l'état haut → MOSFET
passant → ligne automate tirée à 0 V.

⚠️ **23 MOSFET pour 22 voies X** (T13 absent de la numérotation). À vérifier au
schéma : voie de réserve, ou signal supplémentaire non identifié.

### 2. Les 21 entrées Y n'ont aucune protection

La carte ne compte que **quatre résistances** hors étage de sortie : deux
diviseurs (`R30`/`R31` et `R40`/`R41`), vraisemblablement pour une mesure de
tension. **Aucun optocoupleur, aucun diviseur sur les 21 lignes `Y`** : elles
arrivent directement sur les broches du Mega.

Le point bloquant W1b reste donc entier, et il est maintenant confirmé par le
routage : si l'amplitude des lignes `Y` dépasse V_CC, rien ne protège le
microcontrôleur.

### 3. L'alimentation est isolée

Le `TDN 5-2411WISM` est un convertisseur **isolé 1,5 kV**, 5 W. C'est le poste
le plus cher de la carte, et il explique pourquoi la masse de l'AGV et celle de
la logique sont séparées.

---

## Adaptation de niveaux : CONDITIONNEL

⚠️ **Poste chiffré à titre conservatoire, en attente de mesure.**

Le relevé de câblage amène les 21 lignes `Y` **directement** sur des broches de
l'ATmega, sans protection. Leur amplitude n'est pas connue (point bloquant W1b,
phase 1 de [`DEPLOY.md`](DEPLOY.md)).

| Résultat de la mesure sur `Y05` | Matériel à ajouter | *Repère TTC* |
|---|---|---:|
| ≤ V_CC de l'ATmega | rien | **0 €** |
| Légèrement au-dessus | 21 diviseurs résistifs 1 % | *9,60 €* |
| 24 V ou incompatible | 6× `PC847` + résistances + carte fille | *54,00 €* |

Dans le troisième cas, il faut aussi **router une carte fille** : plusieurs
semaines de délai, pas seulement un coût.

## Récapitulatif

| Poste | Total TTC relevé | *Repère TTC* | *Repère HT* |
|---|---:|---:|---:|
| **Carte AGV (nomenclature KiCad)** | ☐ | *121,38 €* | *101,15 €* |
| Harnais de raccordement | ☐ | *41,40 €* | *34,50 €* |
| Poste fixe UniPi | ☐ | *300,00 €* | *250,00 €* |
| Outillage | ☐ | *126,00 €* | *105,00 €* |
| **TOTAL** | **☐** | ***588,78 €*** | ***490,65 €*** |

### Coûts récurrents

| Poste | Annuel |
|---|---:|
| Abonnement opérateur | **0 €** |
| Infrastructure Wi-Fi | à la charge du client (existante) |
| Piles des boutons | **0 €** : PTM 210 auto-alimentés |

### Pourquoi le Gate G100 et non l'E413

Le service du poste n'utilise, en tout et pour tout, **un port série et de
l'Ethernet** : le récepteur EnOcean d'un côté, le broker MQTT de l'autre. Les
boutons étant EnOcean, **aucune entrée TOR n'est utilisée** :
`agv_poste/io_backend.py` n'est même pas appelé par le service.

Payer un automate à entrées/sorties revient donc à financer du matériel qui ne
sert pas.

| | Unipi Gate G100 | Unipi E413 / Patron |
|---|---|---|
| Prix indicatif | **~200 €** | 375 à 479 € |
| Système | **Debian Linux** | à vérifier (§12.9) |
| Ethernet | **2 ports** (Gb + 100M) | 1 |
| USB | 1× USB 3.0, pour le TCM 515 | selon modèle |
| RS485 | 1 (2 isolés sur G110) | selon modèle |
| Alimentation | 6–36 VDC | 24 V |
| Stockage | 16 Go eMMC + microSD | 8 Go eMMC |
| Entrées/sorties TOR | **aucune** | plusieurs : **inutilisées ici** |

Trois gains au-delà du prix :

1. **Le point ouvert §12.9 disparaît.** Le Gate est livré sous **Debian**, donc
   le service Python 3.11 et systemd fonctionnent sans question. L'incertitude
   « Mervis ou Linux ? » qui bloquait le dossier ne se pose plus.
2. **Deux ports Ethernet** permettent de séparer physiquement le VLAN OT du
   raccordement de maintenance : un argument de plus auprès du service
   informatique.
3. **16 Go d'eMMC** au lieu de 8 : de la marge pour le journal d'événements.

Ce raisonnement ne vaut que pour **cette** architecture : le poste LoRa, lui,
doit piloter une radio SX1276 en SPI, ce qu'un boîtier DIN fermé ne permet pas.
Voir [`../A2_LoRa/BOM.md`](../A2_LoRa/BOM.md), section « Pourquoi pas un Unipi Gate
pour ce poste ? ».

Le seul port USB est à surveiller : il est pris par l'adaptateur série du
TCM 515. Si un second périphérique USB devenait nécessaire, passer le TCM 515
en RS485 via un convertisseur TTL/RS485 (~10 €) libère le port.

⚠️ **Prix relevé en 2021 sur un article de presse, à confirmer.** Et la
référence « E413 » du document de planification n'a pas pu être retrouvée au
catalogue Unipi : vérifier qu'elle existe encore avant toute comparaison
formelle.

### Alternative encore moins chère

Si aucun historique long terme n'est attendu, un ESP32 avec module Ethernet
remplit la même fonction pour ~102,00 € au lieu de 300,00 €, soit
**198,00 € d'économie**. Le Gate ne se justifie que par la
persistance, l'hébergement du broker et le fait d'être un matériel industriel
référencé.

---

## Risques d'approvisionnement et délais

| Élément | Délai typique | Risque |
|---|---|---|
| `UniPi E413` | 2 à 6 semaines | **Chemin critique matériel.** Vérifier la référence exacte et le runtime livré (§12.9) avant commande |
| `PTM 210` / `TCM 515` | 1 à 2 semaines | Peu distribués par RS : prévoir un distributeur EnOcean |
| PCB + assemblage de la carte AGV | 3 à 5 semaines | **Chemin critique matériel** : la carte est fabriquée, pas réutilisée |
| `TDN 5-2411WISM` | 1 à 3 semaines | Convertisseur isolé : poste le plus cher de la carte |
| Adaptation de niveaux | 3 à 5 semaines **si nécessaire** | Conditionnel à la mesure W1b : d'où l'urgence de la faire |
| Points d'accès Wi-Fi additionnels | variable | À la charge du client, dépend du relevé 0.2 |

**Ne rien commander avant la phase 1 de [`DEPLOY.md`](DEPLOY.md)** : le relevé de
couverture Wi-Fi peut disqualifier l'architecture, et la mesure d'amplitude
change la nomenclature.

## Ce que cette nomenclature ne couvre pas

- **La main-d'œuvre** : 3 à 5 jours-homme de mise en œuvre, hors développement.
- **Les points d'accès Wi-Fi additionnels**, si le relevé en révèle le besoin.
  À la charge du client, et potentiellement le poste le plus lourd du projet.
- **La carte de rechange** : si la sauvegarde des firmwares d'origine échoue
  (phase 2 de `DEPLOY.md`), il n'y a plus de retour arrière. Prévoir une V5.0.1
  de rechange devient une assurance à chiffrer avec le client.
---

## Analyse critique de la carte routée

Trois observations issues du projet KiCad. Aucune ne remet en cause le routage,
mais deux méritent une décision avant fabrication.

### ⚠️ L'`IRF520` n'est pas un MOSFET « logic-level »

Sa tension de seuil est spécifiée **de 2 à 4 V**, et son `Rds(on)` est garanti à
**Vgs = 10 V**. Attaqué par une broche à 5 V, il conduit, mais hors des
conditions du constructeur, et avec une résistance à l'état passant très
supérieure à celle annoncée.

**Pour les courants en jeu, quelques milliampères sur une entrée d'automate,
cela fonctionne.** La chute de tension reste négligeable même à 10 Ω. Ce n'est
donc pas un défaut bloquant : c'est un choix hors spécification, qu'il faut
connaître avant de l'attribuer à autre chose le jour où une voie se comporte mal
en température.

Si le PCB n'est pas encore fabriqué, deux alternatives valent d'être pesées :

| Solution | Coût | Surface | Remarque |
|---|---:|---|---|
| `IRF520` ×23 (actuel) | ~16,56 € | **23 boîtiers TO-220** | Hors spec à 5 V, très encombrant |
| `IRL520` ×23 | ~30,36 € | idem | Version **logic-level** du même composant, brochage identique : **substitution sans reroutage** |
| `ULN2803A` ×3 | ~4,32 € | 3 boîtiers DIP-18 | Réseau Darlington à collecteur ouvert : même fonction, **résistances de grille supprimées**, surface divisée par dix |

L'`IRL520` est le changement le moins risqué : même boîtier, même brochage,
aucune modification du circuit. L'`ULN2803A` est le plus rationnel si le
routage peut encore bouger, mais il sature à ~1,1 V au lieu de ~0,1 V : **à
valider contre le seuil d'entrée de l'automate** avant de le retenir.

### ⚠️ Isolation : le convertisseur isolé et l'étage à MOSFET se contredisent

Le `TDN 5-2411WISM` est un convertisseur **isolé 1,5 kV** : le poste le plus
cher de la carte. Or les MOSFET de sortie tirent les lignes de l'automate vers
**la masse de la carte** : il y a donc bien une masse commune avec l'automate,
et l'isolation galvanique n'existe pas au niveau des signaux.

Deux lectures possibles, et il faut trancher :

- **l'isolation sert à découpler le 24 V de l'AGV du rail logique** (bruit,
  transitoires du chariot). Elle est alors justifiée, et le convertisseur reste ;
- **l'isolation était censée s'appliquer aux signaux.** Dans ce cas elle est
  inopérante, et un `TSR 1-2450` non isolé à ~8,40 € remplacerait le `TDN`, soit
  **21,60 € d'économie** sur la ligne la plus chère de la carte.

### ⚠️ Le 6 V du `L7806CV` alimente un microcontrôleur prévu pour 5,5 V

Rappel de [`docs/subd25_atmega.md`](docs/subd25_atmega.md) : 6,0 V est le
**maximum absolu** de l'ATmega2560. Le `TDN` fournit déjà un 5 V propre sur la
carte. Si le Mega peut être alimenté depuis ce 5 V, le `L7806CV` devient inutile
et le microcontrôleur revient dans sa plage recommandée.

À vérifier au schéma : le 6 V va-t-il sur `Vin` du module Mega, auquel cas il
est *trop bas* pour son régulateur, ou directement sur `V_CC` ?

---

## Mode d'emploi pour le service achats

1. Rechercher chaque `Réf. fabricant` sur [fr.rs-online.com](https://fr.rs-online.com).
2. Renseigner la référence RS (numéro de stock), le prix unitaire TTC et le total.
3. Si la référence est absente du catalogue RS : chercher sur Amazon, et
   **noter la source dans la colonne `Réf. catalogue`** : la traçabilité de
   l'origine compte autant que le prix.
4. Attention aux **conditionnements** : un IRF520 ou une résistance se vend
   souvent par 5, 10 ou 100. Le prix unitaire affiché peut correspondre à un
   lot entier.
5. Les lignes marquées `PCB` ne sont pas des articles de catalogue : elles
   demandent un devis chez un fabricant de circuits imprimés
   (JLCPCB, Eurocircuits, PCBWay) à partir des fichiers Gerber.
6. Reporter les sous-totaux dans le récapitulatif, puis **mettre à jour
   [`../../docs/COMPARAISON.md`](../../docs/COMPARAISON.md)** si les écarts changent le classement des architectures.

## Équivalences acceptables

Ces substitutions ne changent rien au fonctionnement, et peuvent débloquer une
rupture de stock :

| Référence | Équivalents |
|---|---|
| `IRF520` | `IRL520N` : version **logic-level**, brochage identique |
| `TDN 5-2411WISM` | `TSR 1-2450` **si l'isolation n'est pas requise** : voir l'analyse |
| `L7806CV` | Sans objet si l'ATmega est alimenté depuis le 5 V de la carte |
| `DB25P564CTXLF` | Tout SUB-D 25 coudé CI au même pas |

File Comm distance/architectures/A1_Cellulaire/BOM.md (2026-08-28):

# Nomenclature A1 : Cellulaire + EnOcean (SMS ou LTE-M)

## 💰 Total

| | HT | TTC | *Accessoires écartés* |
|---|---:|---:|---:|
| **A1 : poste ESP32 (recommandé)** | **339,70 €** | **407,64 €** | *+ 86,00 € HT* |
| **A1 : poste Unipi Gate G100** | **368,70 €** | **442,44 €** | *+ 76,00 € HT* |
| **A1 : poste UniPi E413 LTE** | **504,70 €** | **605,64 €** | *+ 93,00 € HT* |

Ces totaux ne comptent que les **composants déterminants**.

Les accessoires arbitrables selon le budget : antennes, boîtiers,
coffrets, enveloppes murales, câbles : sont volontairement **hors
nomenclature** : ils se substituent librement d'un fournisseur à l'autre
et ne changent rien à la conception. La dernière colonne rappelle ce
qu'ils pèsent, pour que ce total ne soit jamais pris pour un coût
d'achat complet.

⚠️ [`../../docs/COMPARAISON.md`](../../docs/COMPARAISON.md) et le `README.md` racine comparent les architectures
**accessoires compris**, sans quoi le classement serait faussé. Leurs
chiffres sont donc plus élevés que ceux-ci, et c'est normal.

## ⚠️ Feuille de sourcing, à compléter avant usage

Ce document est une **liste d'achat à remplir**, pas un devis. Les colonnes
`Réf. catalogue`, `PU TTC` et `Total TTC` sont vides : c'est le service achats
qui les renseigne depuis le catalogue.

| Colonne | Ce qu'elle contient |
|---|---|
| `Réf. fabricant` | **Référence exacte à rechercher** : c'est ce qui rend la ligne non ambiguë |
| `Lien d'achat` | **Recherche pré-remplie chez le distributeur**, RS en premier chaque fois que c'est plausible. Un second lien n'apparaît que lorsque RS ne distribue probablement pas la référence |
| `Réf. catalogue` / `PU TTC` / `Total TTC` | **À remplir** |
| *`Repère TTC`* | Estimation de départ, **en italique** : voir l'avertissement ci-dessous |

### ⚠️ Ce sont des liens de RECHERCHE, pas des fiches produit

Chaque lien lance une **recherche sur la référence fabricant** chez le
distributeur. Aucun numéro de stock n'a été vérifié : le site de RS bloque
l'accès automatisé, il n'était donc pas possible de confirmer qu'une fiche
produit existe ni à quel prix. Inventer des numéros de stock aurait produit des
liens crédibles menant à la mauvaise pièce : le pire résultat possible sur une
liste d'achat.

C'est au service achats de retenir la bonne fiche et d'en reporter la référence
dans la colonne `Réf. catalogue`. Si une recherche RS ne donne rien, la ligne
suit un second lien vers Mouser, Digi-Key ou Amazon.

**RS est mis en tête partout**, y compris sur les références EnOcean et Unipi
qu'il ne distribue habituellement pas : le catalogue évolue, et une commande
groupée chez un fournisseur déjà référencé vaut souvent le surcoût unitaire.

### ⚠️ Les repères ne sont PAS des prix RS

Les repères viennent des nomenclatures d'étude, établies sur des prix de
composants génériques, puis converties en TTC (TVA 20 %). **Chez un
distributeur industriel comme RS, les mêmes références coûtent couramment 2 à
4 fois plus.** Un module ESP32 y est plutôt à 15–25 € qu'à 6 €.

Ces repères servent à deux choses, et à rien d'autre :

- vérifier qu'une ligne relevée au catalogue n'est pas aberrante (erreur de
  référence, conditionnement par 100, prix pour un lot) ;
- garder un ordre de grandeur tant que la feuille n'est pas remplie.

**Le total d'une feuille complétée sera nettement supérieur au total des
repères.** C'est normal, et c'est le prix de la traçabilité d'un distributeur
référencé : disponibilité, garantie, facture, fiches techniques.

### Note pour l'arbitrage

Les prix sont demandés en TTC. Pour une entreprise, **la TVA est récupérable** :
la comparaison entre architectures reste donc pertinente en HT, et
[`../../docs/COMPARAISON.md`](../../docs/COMPARAISON.md) raisonne en HT. Diviser un total TTC par 1,20 donne le HT.

---

### **[A1]** Carte AGV : variante LTE-M

Carte neuve à fabriquer. La V5.0.1 d'origine est **conservée intacte**.

| Désignation | Réf. fabricant | Qté | Lien d'achat | Réf. catalogue | PU TTC | Total TTC | *Repère TTC* |
|---|---|---:|---|---|---:|---:|---:|
| Module MCU, 8 Mo flash | `ESP32-WROOM-32E-N8` | 1 | [RS](https://fr.rs-online.com/web/c/?searchTerm=ESP32-WROOM-32E-N8) | ☐ | ☐ | ☐ | *6,00 €* |
| Modem LTE-M / NB-IoT, très basse consommation | `SIM7080G (SIMCom)` | 1 | [RS](https://fr.rs-online.com/web/c/?searchTerm=SIM7080G) · [Amazon](https://www.amazon.fr/s?k=SIM7080G) | ☐ | ☐ | ☐ | *21,60 €* |
| Support SIM nano, protection ESD | `Molex 785900001` | 1 | [RS](https://fr.rs-online.com/web/c/?searchTerm=Molex+785900001) | ☐ | ☐ | ☐ | *1,80 €* |
| Optocoupleur quadruple : 43 voies | `PC847 (Sharp)` | 11 | [RS](https://fr.rs-online.com/web/c/?searchTerm=PC847) | ☐ | ☐ | ☐ | *7,92 €* |
| Convertisseur DC/DC 24 V → 5 V 1 A | `TSR 1-2450 (Traco Power)` | 1 | [RS](https://fr.rs-online.com/web/c/?searchTerm=TSR+1-2450) | ☐ | ☐ | ☐ | *8,40 €* |
| LDO 3,3 V 600 mA | `AP2112K-3.3TRG1 (Diodes)` | 1 | [RS](https://fr.rs-online.com/web/c/?searchTerm=AP2112K-3.3TRG1) | ☐ | ☐ | ☐ | *0,72 €* |
| Diode TVS protection 24 V | `SMBJ33A (Littelfuse)` | 2 | [RS](https://fr.rs-online.com/web/c/?searchTerm=SMBJ33A) | ☐ | ☐ | ☐ | *1,20 €* |
| **Réservoir capacitif** : pics d'émission modem (2 A) | `470 µF low-ESR 16 V` | 1 | [RS](https://fr.rs-online.com/web/c/?searchTerm=470+%C2%B5F+low-ESR+16+V) | ☐ | ☐ | ☐ | *3,60 €* |
| Résistances 1 %, découplages, LED d'état | `lot` | 1 | - | ☐ | ☐ | ☐ | *9,60 €* |
| ILS (reed) + aimant : Wi-Fi de maintenance | `Standex KSK-1A66 ou équiv.` | 1 | [RS](https://fr.rs-online.com/web/c/?searchTerm=Standex+KSK-1A66) | ☐ | ☐ | ☐ | *2,40 €* |
| SUB-D 25 mâle et femelle, coudés CI | `Amphenol L717SDB25xA4CH4F` | 2 | [RS](https://fr.rs-online.com/web/c/?searchTerm=Amphenol+L717SDB25xA4CH4F) | ☐ | ☐ | ☐ | *7,20 €* |
| PCB 4 couches ~120 × 100 mm (série de 5) | `Gerber projet` | 1 | [JLCPCB](https://jlcpcb.com/quote) · [PCBWay](https://www.pcbway.com/orderonline.aspx) | ☐ | ☐ | ☐ | *14,40 €* |
| **Sous-total** | | | | | | **☐** | ***84,84 €*** |

### Interface bus : variante `shift595` (recommandée)

| Désignation | Réf. fabricant | Qté | Lien d'achat | Réf. catalogue | PU TTC | Total TTC | *Repère TTC* |
|---|---|---:|---|---|---:|---:|---:|
| Registre à décalage sortie 8 bits | `SN74HC595N (TI)` | 3 | [RS](https://fr.rs-online.com/web/c/?searchTerm=SN74HC595N) | ☐ | ☐ | ☐ | *1,80 €* |
| Registre à décalage entrée 8 bits | `SN74HC165N (TI)` | 3 | [RS](https://fr.rs-online.com/web/c/?searchTerm=SN74HC165N) | ☐ | ☐ | ☐ | *1,80 €* |
| **Sous-total** | | | | | | **☐** | ***3,60 €*** |
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

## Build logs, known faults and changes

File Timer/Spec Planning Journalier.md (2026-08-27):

# Spécification : Planning journalier des déplacements (carte AGV V5.0.1)

> Document de cadrage destiné à l'implémentation. Il fixe les décisions prises,
> signale les points encore ouverts et ne présume pas du découpage en modules.

---

## 1. Objectif

Permettre le déclenchement automatique de missions de déplacement AGV à des
horaires programmés, configurables depuis une interface web (modèle `agvdump`),
sur la base de la date et de l'heure.

**Changement de nature à retenir :** on passe d'un système d'appel à la demande
par un opérateur à un déclenchement autonome sur horloge. Ce n'est pas une simple
fonctionnalité logicielle (voir §9).

---

## 2. Source de temps

### 2.1 Décision

| Élément | Choix | Justification |
|---|---|---|
| Horloge de travail | Heure système ESP32 (`esp_timer`, quartz 40 MHz) | Dérive 10–50 ppm, soit quelques secondes/jour. Suffisant entre deux resynchronisations. |
| Référence persistante | **DS3231** sur I²C, adresse `0x68` | TCXO ±2 ppm, pile CR2032. Aucun conflit avec les MCP23017 (`0x20`–`0x27`). |
| Resynchronisation | NTP pendant les fenêtres de maintenance → écriture DS3231 | Corrige la dérive cumulée. |
| Fuseau horaire | `setenv("TZ", ...)` + `tzset()` | Gère les transitions été/hiver automatiquement. |

### 2.2 Bibliothèque `ESP32Time` : écartée

Ce n'est pas une base de temps : c'est une surcouche Arduino autour de
`settimeofday()` / `localtime_r()`. Elle n'apporte rien que la libc de l'ESP-IDF
ne fournisse déjà, et ne traite aucun des deux points bloquants :

- **Perte à la coupure d'alimentation.** L'heure vit en `RTC_SLOW_MEM` : elle
  survit au deep sleep, pas à une mise hors tension. Redémarrage à l'epoch 1970.
- **Aucun drapeau de non-fiabilité.** `getEpoch()` renvoie toujours une valeur,
  sans dire si elle vient d'une synchro réelle ou d'un compteur reparti de zéro.

S'ajoute que sa gestion du fuseau se limite à un offset fixe en secondes (pas de
DST), et que le projet est en **ESP-IDF/PlatformIO** : tirer le core Arduino en
composant pour ce wrapper n'a pas d'intérêt.

### 2.3 État de confiance de l'heure

Machine à trois états, exposée dans la télémétrie et l'IHM :

- `TIME_UNTRUSTED` : **planning gelé**, alarme IHM
- `TIME_RTC` : heure issue du DS3231, exécution autorisée
- `TIME_NTP` : resynchronisée récemment

Une heure fausse, sur un système qui déclenche des déplacements, est pire qu'une
absence d'heure. Le passage en `TIME_UNTRUSTED` doit être franc et visible.

### 2.4 Séquence de boot

```c
// Au démarrage
if (ds3231_read(&tm, &osf) != OK || osf || tm.tm_year < 124) {
    time_state = TIME_UNTRUSTED;   // planning gelé + alarme IHM
} else {
    struct timeval tv = { .tv_sec = mktime_utc(&tm) };
    settimeofday(&tv, NULL);
    time_state = TIME_RTC;
}

setenv("TZ", "CET-1CEST,M3.5.0,M10.5.0/3", 1);
tzset();

// Toutes les heures       : relecture DS3231, correction de la dérive esp_timer
// Fenêtre de maintenance  : NTP -> écriture DS3231 -> time_state = TIME_NTP
```

Le bit `OSF` (oscillator stop flag) du DS3231 est le signal de non-fiabilité :
il indique que l'oscillateur s'est arrêté depuis la dernière lecture.

**Règle transverse :** tout est stocké et manipulé en **UTC** en interne. La
conversion en heure locale n'intervient qu'à l'affichage et à l'évaluation des
règles de planning.

---

## 3. Modèle de données

### 3.1 Entrée de planning

Pas de cron brut : illisible pour l'exploitant.

| Champ | Contenu |
|---|---|
| `id` | UUID court, stable |
| `enabled` | actif / suspendu |
| `heure` | HH:MM, heure locale |
| `jours` | masque binaire lun–dim |
| `validite` | date de début / fin (optionnelle) |
| `exceptions` | liste de dates exclues (fériés, congés) |
| `mission` | station de destination (1–1024) + bits de commande |
| `priorite` | arbitrage si deux entrées coïncident |

### 3.2 Validation quotidienne

Champs de niveau document, **distincts des entrées** :

| Champ | Rôle |
|---|---|
| `valide_pour` | date AAAA-MM-JJ |
| `valide_par` | identifiant opérateur |
| `valide_le` | horodatage |

**Règle centrale :** le moteur refuse toute exécution si
`valide_pour != date_du_jour`. Le planning persiste ; c'est son autorisation
d'exécution qui expire chaque jour. Rien n'est effacé, mais rien ne part sans un
geste explicite.

`valide_par` + `valide_le` fournissent au passage la traçabilité de qui a
autorisé quels déplacements : utile le jour où il y a un incident.

### 3.3 Persistance

- JSON sur **LittleFS**
- En-tête avec **CRC32** et **numéro de version de schéma**
- Écriture **atomique** : fichier temporaire puis `rename`
- Conservation de la version N-1 pour rollback si le CRC échoue au boot

---

## 4. Moteur d'ordonnancement

### 4.1 Contrainte d'architecture

Le cœur est du **C++ pur**, sans dépendance Arduino ni ESP-IDF, avec une horloge
injectable :

```cpp
time_t next_occurrence(const Entry& e, time_t now);
```

Testable sur PC avec une horloge simulée. Une semaine de planning se valide en
quelques millisecondes. Même approche que le codec de trames LoRa.

### 4.2 Sémantiques à trancher explicitement

Faute de décision explicite, ces trois cas se tranchent tout seuls, et mal.

**Rattrapage.** L'AGV était occupé ou hors tension à 14:00 ; que fait-on à 14:07 ?
→ Fenêtre de grâce paramétrable (défaut suggéré : 5 min). Au-delà : saut +
journalisation. **Ne jamais rejouer la journée entière au redémarrage.**

**Idempotence.** Clé d'occurrence = `id_entrée + date_locale`, marquée comme
consommée. Règle au passage le changement d'heure d'automne, où 02:30 existe deux
fois.

**Changement d'heure de printemps.** Les entrées entre 02:00 et 03:00 n'existent
pas ce jour-là. Choix à faire : exécution à 03:00 ou saut, mais l'IHM doit
l'indiquer.

---

## 5. Chaînon vers le bus X/Y

**Le planning n'écrit jamais directement sur les MCP23017.** Il produit une
*mission*, consommée par un séquenceur :

1. Pose de l'adresse station sur les 22 signaux X
2. Respect du `t_setup` (**valeur non encore mesurée : voir §10**)
3. Attente d'acquittement sur les signaux Y
4. Timeout + retry borné
5. Refus d'empiler une nouvelle destination tant que la précédente n'est pas
   acquittée

### Répartition ESP32 / ATmega2560

| Rôle | Cible |
|---|---|
| Temps, stockage, web, décision | ESP32 |
| Séquencement déterministe sur le bus | ATmega2560 *(si la mesure de `t_setup` le confirme)* |

**Heartbeat entre les deux :** si l'ATmega ne voit plus l'ESP32 pendant N
secondes, il refuse les missions issues du planning.

---

## 6. Interface web

Modèle `agvdump` : REST pour la configuration, WebSocket pour le temps réel.

```
GET    /api/planning          → liste + version (ETag)
PUT    /api/planning          → remplacement complet, 409 si version périmée
GET    /api/planning/next     → 10 prochaines occurrences calculées
POST   /api/planning/pause    → suspension globale
POST   /api/planning/skip     → saute la prochaine occurrence
GET    /api/time              → heure RTC, source, dérive estimée
POST   /api/planning/validate → validation de la journée
```

**Contrôle de version optimiste (ETag / 409)** : évite qu'un second navigateur
écrase silencieusement les modifications du premier. Cas fréquent dès qu'il y a
un poste atelier et un poste bureau.

### Affichage

La vue la plus utile est la **liste des prochaines occurrences calculées**, pas
la liste des règles : c'est ce qui permet à l'exploitant de vérifier qu'il a bien
compris ce qu'il a saisi.

### Bandeau de validation (non contournable)

```
Planning du 27/08 non validé : aucun déplacement automatique
Planning en mémoire : 6 missions (dernière validation : 26/08 par M. Dupont)
[ Reprendre le planning d'hier ]  [ Modifier ]  [ Valider la journée ]
```

Le bouton « reprendre hier » n'est pas cosmétique : si les journées se
ressemblent, imposer une ressaisie complète pousse les gens à contourner le
système. Un clic de confirmation obtient le même engagement conscient sans la
friction.

**Rappel actif :** à 06:30, si la journée n'est pas validée alors que des
missions étaient prévues → voyant pupitre ou notification. C'est ce qui manque à
un rappel purement passif : sans cela, l'opérateur découvre l'absence de planning
par l'absence de mouvement, indiscernable d'une panne.

---

## 7. Reboot quotidien

### 7.1 Retenu, mais pour une autre raison que celle envisagée

**Écarté comme mécanisme d'effacement du planning.** Utiliser un mode de
défaillance comme fonctionnalité pose trois problèmes : perte de données réelle
(planning du lendemain saisi à 17h, effacé à 03:00), signal muet (personne n'est
prévenu), et fragilité (le jour où le reboot échoue, le rappel disparaît sans
que personne ne s'en aperçoive). Remplacé par la validation quotidienne (§3.2).

**Retenu comme exercice du chemin de démarrage.** Un reboot programmé quotidien
fait apparaître les bugs de boot (RTC illisible, LittleFS corrompu, séquenceur
mal réinitialisé) en phase de mise au point plutôt que six mois plus tard lors
du premier redémarrage réel. Argument valable surtout en prototype.

### 7.2 Note technique

Sur un redémarrage **logiciel** (`esp_restart()`), le domaine RTC n'est pas coupé
et l'ESP-IDF restitue l'heure système au boot. Le reboot programmé ne fait donc
pas perdre l'heure : contrairement à une coupure d'alimentation ou un brownout.
Cela ne dispense pas du DS3231 : disjoncteur, maintenance et déplacement de
l'AGV restent des scénarios réels.

### 7.3 Verrous obligatoires

- Fenêtre à heure creuse (suggéré : **03:00**)
- **Interdiction de reboot si une mission est en cours ou si l'AGV n'est pas à
  quai.** Un redémarrage en cours de déplacement relâche les sorties X sans que
  le contrôleur MEIDEN en soit informé.

### 7.4 Instrumentation mémoire, à faire indépendamment

Si le heap se dégrade au fil des jours, c'est une fuite ou une fragmentation. Le
reboot la **masque** au lieu de la corriger. Risque : livrer un système qui fuit
à 200 o/h, invisible six mois, puis qui plante en trois jours.

À exposer en télémétrie et dans l'IHM :

```c
esp_get_free_heap_size();          // heap courant
esp_get_minimum_free_heap_size();  // plancher depuis le boot
esp_reset_reason();                // journalisé à chaque démarrage
```

Un plancher décroissant de façon monotone sur une semaine = fuite. Suspects
habituels sur ce type de carte : buffers WebSocket par client, parsing JSON à
chaque requête, sockets de clients déconnectés brutalement non libérés.

---

## 8. Journalisation

Journal circulaire horodaté, exportable en **CSV** :

- Missions exécutées / sautées (avec motif du saut)
- Validations quotidiennes (`valide_par`, `valide_le`)
- Transitions d'état de l'heure
- `esp_reset_reason()` à chaque démarrage

Utile pour la démonstration client autant que pour le débogage.

---

## 9. Sécurité machine, à traiter avant le codage

Le passage au déclenchement autonome sur horloge est un **changement de mode de
fonctionnement au sens sécurité machine**. L'**EN ISO 3691-4** s'applique aux
AGV : l'analyse de risques est à reprendre (scénario type : personne présente sur
le trajet à 06:00 alors que personne n'a rien demandé).

Minimum à prévoir :

- **Sélecteur physique « autorisation planning »** en série avec l'exécution
- **Authentification** sur l'interface web : elle commande désormais un véhicule,
  plus seulement une consultation
- Journal horodaté (§8)

---

## 10. Points ouverts

| Point | Nature | Impact |
|---|---|---|
| `t_setup` du bus X/Y | **Mesure physique requise** | Détermine si l'ATmega2560 doit être conservé pour le séquencement |
| DST de printemps (02:00–03:00) | Décision produit | Exécution à 03:00 ou saut |
| Fenêtre de grâce du rattrapage | Décision produit | Valeur par défaut suggérée : 5 min |
| Capacité du bus I²C / pull-ups | Vérification | Ajout du DS3231 sur les lignes existantes |
| Diffusion NTP depuis le poste fixe | Option | Possible si le poste fixe est conservé (Ethernet filaire), mais réintroduit une dépendance radio pour une fonction qui doit rester autonome. Le DS3231 reste la référence locale dans tous les cas. |

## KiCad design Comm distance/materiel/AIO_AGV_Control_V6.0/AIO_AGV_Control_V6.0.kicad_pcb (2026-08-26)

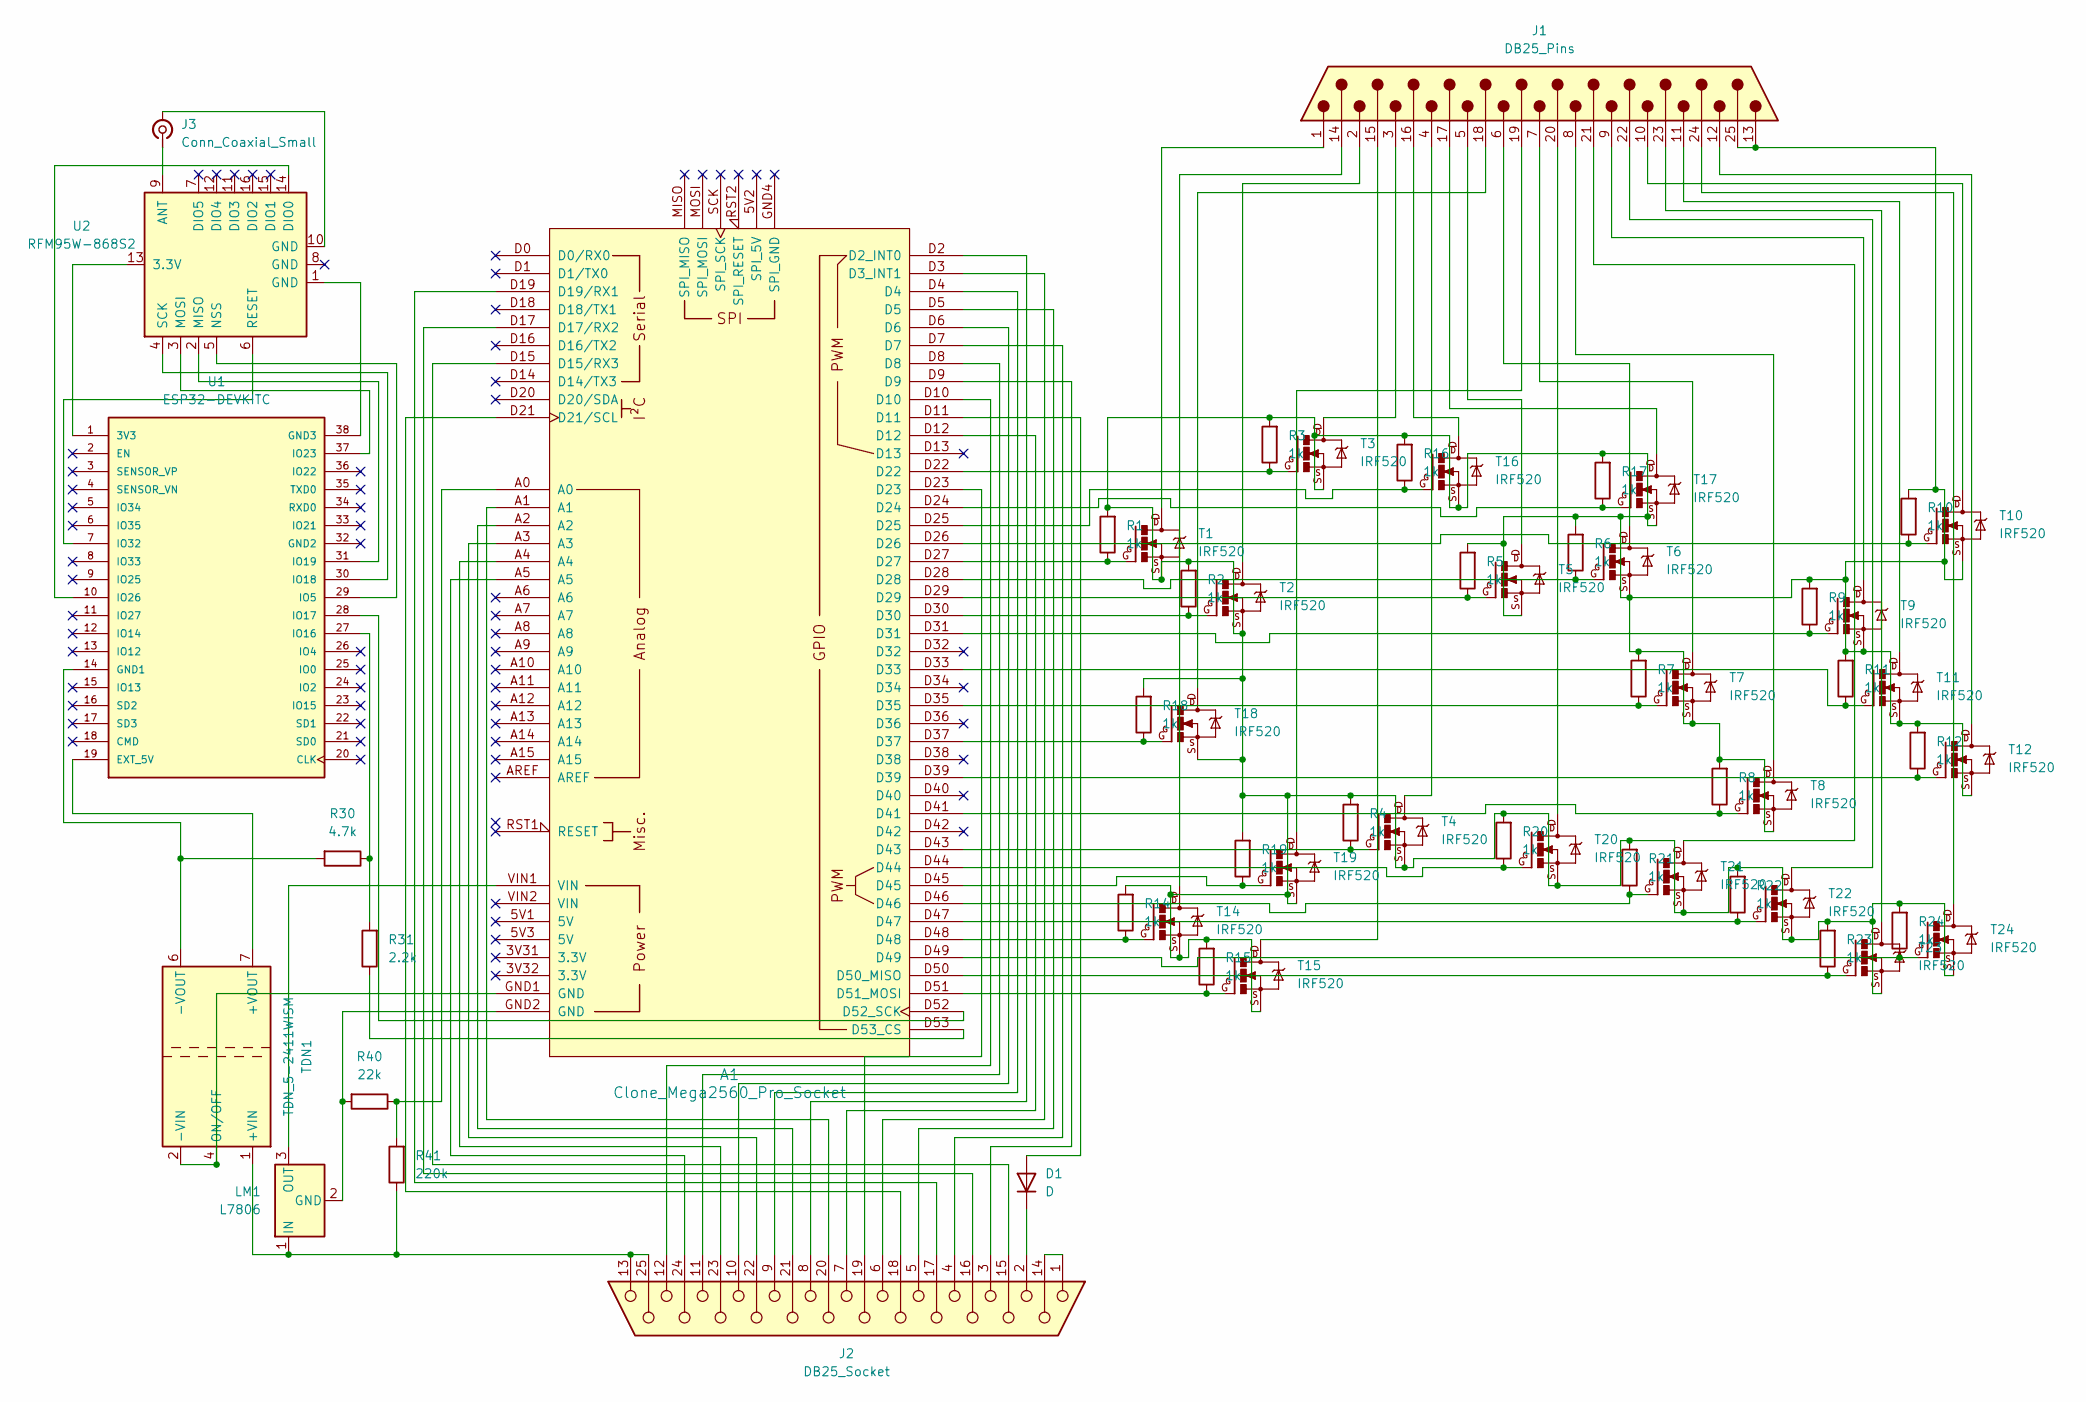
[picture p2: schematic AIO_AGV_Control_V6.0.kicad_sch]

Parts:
A1: Clone_Mega2560_Pro_Socket
D1: D; D_DO-41_SOD81_P10.16mm_Horizontal
J1: DB25_Pins; AMPHENOL_DB25P564CTXLF
J2: DB25_Socket; AMPHENOL_DB25S564GTLF
J3: Conn_Coaxial_Small; SMA_Amphenol_901-143_Horizontal
LM1: L7806; TO255P1020X450X1968-3B
R1, R2, R3, R4, R5, R6, R7, R8, R9, R10, R11, R12, R14, R15, R16, R17, R18, R19, R20, R21, R22, R23, R24: 1k; R_Axial_DIN0411_L9.9mm_D3.6mm_P12.70mm_Horizontal
R30: 4.7k; R_Axial_DIN0411_L9.9mm_D3.6mm_P12.70mm_Horizontal
R31: 2.2k; R_Axial_DIN0411_L9.9mm_D3.6mm_P12.70mm_Horizontal
R40: 22k; R_Axial_DIN0411_L9.9mm_D3.6mm_P12.70mm_Horizontal
R41: 220k; R_Axial_DIN0411_L9.9mm_D3.6mm_P12.70mm_Horizontal
T1, T2, T3, T4, T5, T6, T7, T8, T9, T10, T11, T12, T14, T15, T16, T17, T18, T19, T20, T21, T22, T23, T24: IRF520; TO220BV
TDN1: TDN_5-2411WISM; Converter_DCDC_TRACO_TDN_5-xxxxWISM_SMD
U1: ESP32-DEVKITC; MODULE_ESP32-DEVKITC; PARTREV N/A
U2: RFM95W-868S2; HOPERF_RFM9XW_SMD

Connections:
unnamed: A1.D2 (D2_INT0), J2.8
unnamed: A1.D3 (D3_INT1), J2.6
unnamed: A1.D15 (D15/RX3), J2.15
unnamed: A1.D17 (D17/RX2), J2.16
unnamed: A1.D19 (D19/RX1), J2.17
unnamed: A1.D21 (D21/SCL), J2.18
unnamed: A1.D50 (D50_MISO), R23.1, T23.G
unnamed: A1.D51 (D51_MOSI), R15.1, T15.G
unnamed: A1.D52 (D52_SCK), U1.28 (IO17)
unnamed: A1.D53 (D53_CS), R31.1
unnamed: A1.A0, R40.1, R41.2
unnamed: A1.D4, J2.9
unnamed: A1.D5, J2.5
unnamed: A1.D6, J2.10
unnamed: A1.D7, J2.4
unnamed: A1.D8, J2.11
unnamed: A1.D9, J2.3
unnamed: A1.D10, J2.12
unnamed: A1.D12, J2.7
unnamed: A1.D22, R3.1, T3.G
unnamed: A1.D24, R17.1, T17.G
unnamed: A1.D25, R16.1, T16.G
unnamed: A1.D26, R10.1, T10.G
unnamed: A1.D27, R1.1, T1.G
unnamed: A1.D28, R6.1, T6.G
unnamed: A1.D29, R5.1, T5.G
unnamed: A1.D30, R2.1, T2.G
unnamed: A1.D31, R9.1, T9.G
unnamed: A1.D33, R11.1, T11.G
unnamed: A1.D35, R7.1, T7.G
unnamed: A1.D37, R18.1, T18.G
unnamed: A1.D39, R12.1, T12.G
unnamed: A1.D41, R8.1, T8.G
unnamed: A1.D43, R4.1, T4.G
unnamed: A1.D44, R20.1, T20.G
unnamed: A1.D45, R19.1, T19.G
unnamed: A1.D46, R21.1, T21.G
unnamed: A1.D47, R22.1, T22.G
unnamed: A1.D48, R14.1, T14.G
unnamed: A1.D49, R24.1, T24.G
unnamed: A1.D11, D1.2 (A)
unnamed: D1.1 (K), J2.2
unnamed: J1.14, T14.D
unnamed: J1.15, T15.D
unnamed: J1.16, T16.D
unnamed: J1.17, T17.D
unnamed: J1.18, T18.D
unnamed: J1.19, T19.D
unnamed: J1.20, T20.D
unnamed: J1.21, T21.D
unnamed: J1.22, T22.D
unnamed: J1.23, T23.D
unnamed: J1.24, T24.D
unnamed: J1.13, J1.25, R1.2, R2.2, R3.2, R4.2, R5.2, R6.2, R7.2, R8.2, R9.2, R10.2, R11.2, R12.2, R14.2, R15.2, R16.2, R17.2, R18.2, R19.2, R20.2, R21.2, R22.2, R23.2, R24.2, T1.S, T2.S, T3.S, T4.S, T5.S, T6.S, T7.S, T8.S, T9.S, T10.S, T11.S, T12.S, T14.S, T15.S, T16.S, T17.S, T18.S, T19.S, T20.S, T21.S, T22.S, T23.S, T24.S
unnamed: J1.1, T1.D
unnamed: J1.2, T2.D
unnamed: J1.3, T3.D
unnamed: J1.4, T4.D
unnamed: J1.5, T5.D
unnamed: J1.6, T6.D
unnamed: J1.7, T7.D
unnamed: J1.8, T8.D
unnamed: J1.9, T9.D
unnamed: J1.10, T10.D
unnamed: J1.11, T11.D
unnamed: J1.12, T12.D
unnamed: J2.1, J2.14
unnamed: A1.D23, J2.19
unnamed: A1.A1, J2.20
unnamed: A1.A2, J2.21
unnamed: A1.A3, J2.22
unnamed: A1.A4, J2.23
unnamed: A1.A5, J2.24
unnamed: J2.13, J2.25, LM1.1 (IN), R41.1, TDN1.1 (+VIN)
unnamed: J3.2 (Ext), U2.10 (GND)
unnamed: J3.1 (In), U2.9 (ANT)
unnamed: A1.GND2 (GND), LM1.2 (GND), R40.2
unnamed: A1.VIN1 (VIN), LM1.3 (OUT)
unnamed: TDN1.7 (+VOUT), U1.19 (EXT_5V)
unnamed: A1.GND1 (GND), TDN1.2 (-VIN), TDN1.4 (ON/OFF)
unnamed: R30.2, TDN1.6 (-VOUT), U1.14 (GND1)
unnamed: U1.1 (3V3), U2.13 (3.3V)
unnamed: U1.38 (GND3), U2.1 (GND)
unnamed: U1.29 (IO5), U2.5 (NSS)
unnamed: R30.1, R31.2, U1.27 (IO16)
unnamed: U1.30 (IO18), U2.4 (SCK)
unnamed: U1.31 (IO19), U2.2 (MISO)
unnamed: U1.37 (IO23), U2.3 (MOSI)
unnamed: U1.10 (IO26), U2.14 (DIO0)
unnamed: U1.7 (IO32), U2.6 (RESET)

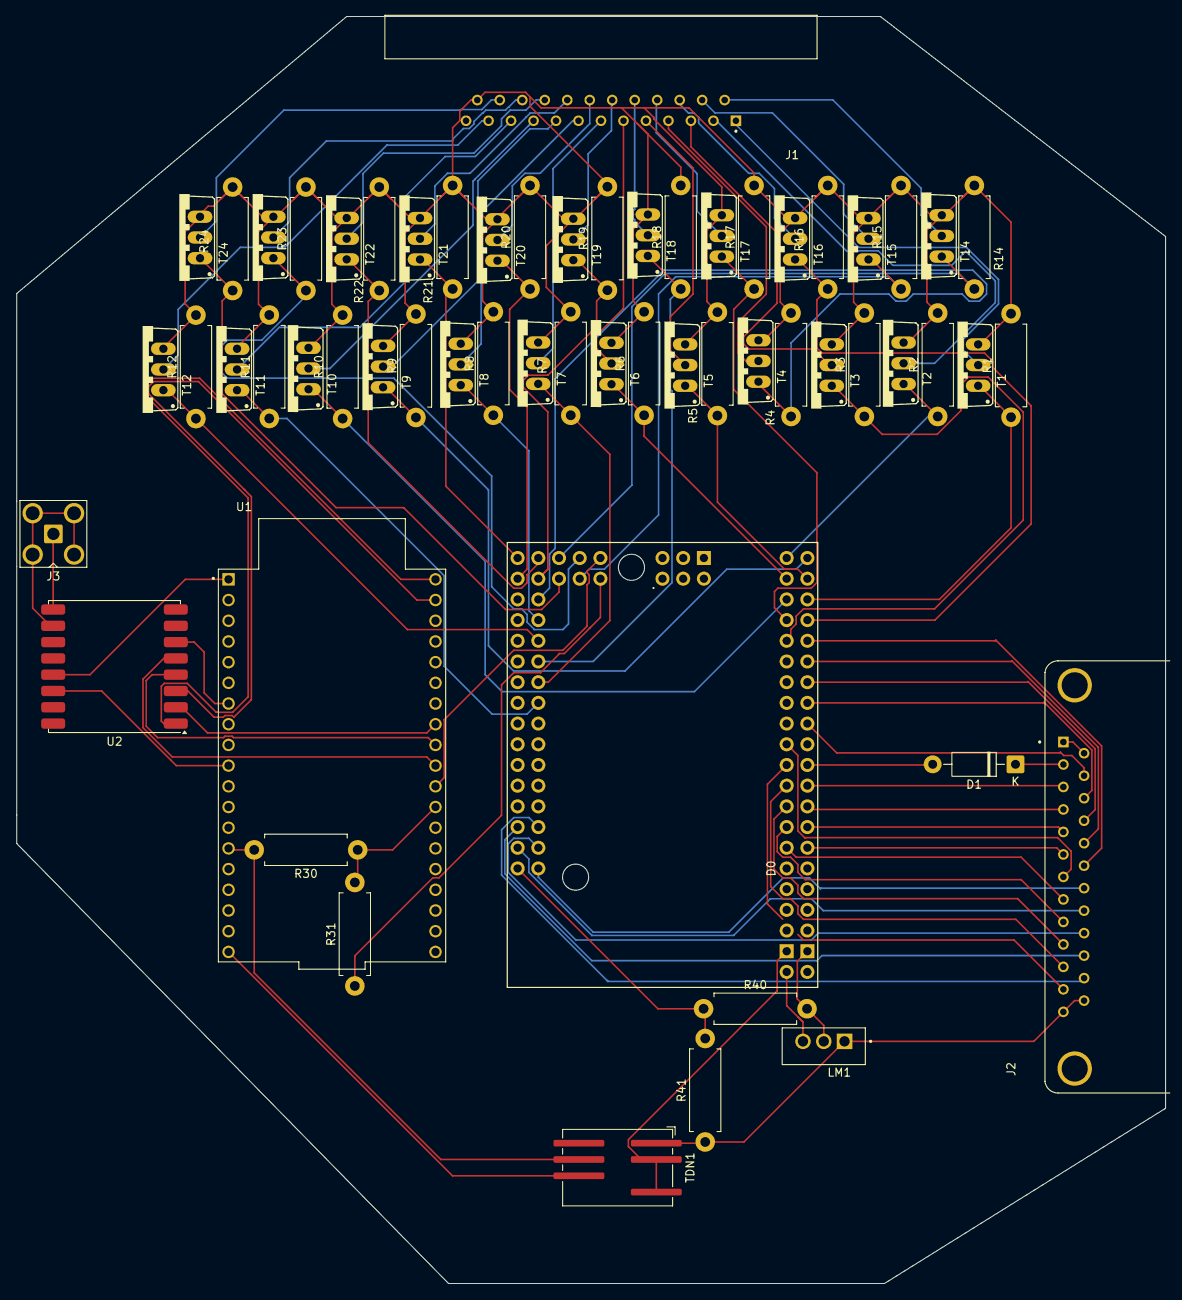
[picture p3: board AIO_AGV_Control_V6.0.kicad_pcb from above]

Board: 2 copper layers, 141.0 x 155.5 mm, 59 parts (0 on the bottom side), 90 nets.

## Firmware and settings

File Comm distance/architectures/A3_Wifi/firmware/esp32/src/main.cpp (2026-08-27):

// Firmware ESP32 de la carte AIO AGV Control V5.0.1 : RÉÉCRIT.
//
// Changement de rôle par rapport à l'existant (planification §1) :
//   avant : point d'accès `agv_atelier`, piloté par l'application mobile
//   après : CLIENT du réseau Wi-Fi d'entreprise, piloté en MQTT par le poste
//
// Responsabilités (planification §2.6 à §2.8) :
//   - client Wi-Fi STA avec reconnexion et IP statique ;
//   - client MQTT : publication `state`/`ack`, abonnement `cmd`, LWT ;
//   - heartbeat vers l'ATmega : c'est ce qui autorise l'AGV à rouler ;
//   - point d'accès de maintenance à la demande, servant `/agvdump`.
//
// L'ESP32 NE TOUCHE JAMAIS AU BUS MEIDEN. Toute la commande passe par
// l'ATmega, qui reste maître de la sécurité de repli.
#include <freertos/FreeRTOS.h>
#include <freertos/task.h>

#include <esp_event.h>
#include <esp_log.h>
#include <esp_netif.h>
#include <esp_wifi.h>
#include <mqtt_client.h>
#include <nvs_flash.h>

#include <cstring>

#include "app/agvdump.h"
#include "app/gateway_app.h"
#include "board_pins.h"
#include "config/hardware_profile.h"
#include "maintenance_ap.h"
#include "platform/esp32/esp_ports.h"

namespace {

const char* TAG = "agv-esp32";

agv::esp32::EspClock g_clock;
agv::esp32::EspUart g_link_uart;
agv::GatewayApp* g_gateway = nullptr;
esp_mqtt_client_handle_t g_mqtt = nullptr;
bool g_wifi_up = false;
bool g_mqtt_up = false;

// --- Ports de la passerelle ------------------------------------------------

class UartLinkPort final : public agv::ILinkPort {
 public:
  void write(const uint8_t* data, size_t len) override { g_link_uart.write(data, len); }
};

class EspMqttPublisher final : public agv::IMqttPublisher {
 public:
  bool publish(const char* topic, const char* payload, bool retain) override {
    if (g_mqtt == nullptr || !g_mqtt_up) return false;
    const int id = esp_mqtt_client_publish(g_mqtt, topic, payload, 0,
                                           agv::default_profile().mqtt.qos, retain ? 1 : 0);
    return id >= 0;
  }
  bool connected() const override { return g_mqtt_up; }
};

UartLinkPort g_link_port;
EspMqttPublisher g_publisher;

// --- Wi-Fi -----------------------------------------------------------------

void on_wifi_event(void*, esp_event_base_t base, int32_t id, void* data) {
  if (base == WIFI_EVENT && id == WIFI_EVENT_STA_START) {
    esp_wifi_connect();
  } else if (base == WIFI_EVENT && id == WIFI_EVENT_STA_DISCONNECTED) {
    g_wifi_up = false;
    // Reconnexion immédiate : en mouvement, chaque seconde de coupure est une
    // commande potentiellement perdue. Le heartbeat vers l'ATmega continue
    // pendant ce temps : la carte n'est pas en défaut, c'est le réseau.
    ESP_LOGW(TAG, "Wi-Fi perdu, reconnexion");
    esp_wifi_connect();
  } else if (base == IP_EVENT && id == IP_EVENT_STA_GOT_IP) {
    g_wifi_up = true;
    const auto* event = static_cast<ip_event_got_ip_t*>(data);
    ESP_LOGI(TAG, "Wi-Fi OK, IP=" IPSTR, IP2STR(&event->ip_info.ip));
  }
}

void start_wifi(const agv::HardwareProfile& profile) {
  esp_netif_init();
  esp_event_loop_create_default();
  esp_netif_t* netif = esp_netif_create_default_wifi_sta();

  if (profile.wifi.use_static_ip) {
    // IP statique : supprime le délai DHCP à chaque handover entre AP
    // (planification §1.4). Sur un AGV en mouvement, ce délai est la première
    // cause de commande perdue.
    esp_netif_dhcpc_stop(netif);
    esp_netif_ip_info_t ip = {};
    ip.ip.addr = esp_ip4addr_aton(profile.wifi.static_ip);
    ip.gw.addr = esp_ip4addr_aton(profile.wifi.gateway);
    ip.netmask.addr = esp_ip4addr_aton(profile.wifi.netmask);
    esp_netif_set_ip_info(netif, &ip);
  }

  wifi_init_config_t init = WIFI_INIT_CONFIG_DEFAULT();
  esp_wifi_init(&init);
  esp_event_handler_instance_register(WIFI_EVENT, ESP_EVENT_ANY_ID, on_wifi_event, nullptr,
                                      nullptr);
  esp_event_handler_instance_register(IP_EVENT, IP_EVENT_STA_GOT_IP, on_wifi_event, nullptr,
                                      nullptr);

  wifi_config_t cfg = {};
  std::strncpy(reinterpret_cast<char*>(cfg.sta.ssid), profile.wifi.ssid,
               sizeof(cfg.sta.ssid) - 1);
  std::strncpy(reinterpret_cast<char*>(cfg.sta.password), profile.wifi.password,
               sizeof(cfg.sta.password) - 1);
  // Roaming : on accepte de changer d'AP dès que le niveau se dégrade.
  cfg.sta.scan_method = WIFI_ALL_CHANNEL_SCAN;
  cfg.sta.sort_method = WIFI_CONNECT_AP_BY_SIGNAL;

  esp_wifi_set_mode(WIFI_MODE_STA);
  esp_wifi_set_config(WIFI_IF_STA, &cfg);
  esp_wifi_set_ps(WIFI_PS_NONE);  // pas d'économie d'énergie : latence d'abord
  esp_wifi_start();
}

int16_t wifi_rssi() {
  wifi_ap_record_t ap;
  if (esp_wifi_sta_get_ap_info(&ap) != ESP_OK) return 0;
  return static_cast<int16_t>(ap.rssi);
}

// --- MQTT ------------------------------------------------------------------

void on_mqtt_event(void*, esp_event_base_t, int32_t id, void* data) {
  auto* event = static_cast<esp_mqtt_event_handle_t>(data);
  const agv::HardwareProfile& profile = agv::default_profile();

  switch (static_cast<esp_mqtt_event_id_t>(id)) {
    case MQTT_EVENT_CONNECTED: {
      g_mqtt_up = true;
      esp_mqtt_client_subscribe(g_mqtt, g_gateway->topic_cmd(), profile.mqtt.qos);
      // Contrepartie du Last Will : on annonce explicitement la présence.
      esp_mqtt_client_publish(g_mqtt, g_gateway->topic_status(), "online", 0, profile.mqtt.qos,
                              1);
      ESP_LOGI(TAG, "MQTT connecté, abonné à %s", g_gateway->topic_cmd());
      break;
    }
    case MQTT_EVENT_DISCONNECTED:
      g_mqtt_up = false;
      ESP_LOGW(TAG, "MQTT déconnecté");
      break;
    case MQTT_EVENT_DATA: {
      // Charge utile terminée par un zéro avant analyse : esp-mqtt ne le
      // garantit pas, et l'analyseur JSON travaille sur une chaîne C.
      static char payload[512];
      const int n = (event->data_len < static_cast<int>(sizeof(payload)) - 1)
                        ? event->data_len
                        : static_cast<int>(sizeof(payload)) - 1;
      std::memcpy(payload, event->data, n);
      payload[n] = '\0';
      g_gateway->on_mqtt_command(payload);
      break;
    }
    default:
      break;
  }
}

void start_mqtt(const agv::HardwareProfile& profile) {
  esp_mqtt_client_config_t cfg = {};
  static char uri[96];
  std::snprintf(uri, sizeof(uri), "%s://%s:%u", profile.mqtt.tls ? "mqtts" : "mqtt",
                profile.mqtt.host, static_cast<unsigned>(profile.mqtt.port));
  cfg.broker.address.uri = uri;
  cfg.credentials.client_id = profile.mqtt.client_id;
  cfg.credentials.username = profile.mqtt.username;
  cfg.credentials.authentication.password = profile.mqtt.password;
  cfg.session.keepalive = static_cast<int>(profile.mqtt.keepalive_s);
  // Last Will and Testament : le broker annonce la perte de l'AGV sans
  // attendre l'expiration d'un chien de garde applicatif (planification §2).
  cfg.session.last_will.topic = g_gateway->topic_status();
  cfg.session.last_will.msg = "offline";
  cfg.session.last_will.qos = profile.mqtt.qos;
  cfg.session.last_will.retain = 1;

  g_mqtt = esp_mqtt_client_init(&cfg);
  esp_mqtt_client_register_event(g_mqtt, MQTT_EVENT_ANY, on_mqtt_event, nullptr);
  esp_mqtt_client_start(g_mqtt);
}

// --- Tâches ----------------------------------------------------------------

// Liaison série vers l'ATmega : lecture continue + heartbeat + interrogation.
void link_task(void*) {
  uint8_t buf[64];
  for (;;) {
    const size_t n = g_link_uart.read(buf, sizeof(buf));
    for (size_t i = 0; i < n; ++i) g_gateway->on_link_byte(buf[i]);
    g_gateway->tick();
    vTaskDelay(pdMS_TO_TICKS(10));
  }
}

// Point d'accès de maintenance, ouvert sur contact ILS (planification §2.8).
void maintenance_task(void*) {
  const agv::HardwareProfile& profile = agv::default_profile();
  agv::maintenance::AccessPoint ap(profile, g_clock);
  ap.set_dump_source([](char* out, size_t cap) {
    const agv::GatewayStats& st = g_gateway->stats();
    agv::AgvDumpInput in;
    in.state = &g_gateway->state();
    in.profile_name = agv::default_profile().name;
    in.uptime_s = g_clock.now_ms() / 1000u;
    in.link_up = g_gateway->link_up();
    in.wifi_up = g_wifi_up;
    in.mqtt_up = g_mqtt_up;
    in.rssi_dbm = wifi_rssi();
    in.ssid = agv::default_profile().wifi.ssid;
    in.heartbeats_sent = st.heartbeats_sent;
    in.link_timeouts = st.link_timeouts;
    in.cmd_expired = st.cmd_expired;
    in.cmd_duplicate = st.cmd_duplicate;
    return agv::render_agvdump(in, out, cap);
  });

  agv::esp32::EspGpio gpio;
  gpio.configure_input(agv::board::kMaintenanceReed, true);
  for (;;) {
    if (!gpio.get(agv::board::kMaintenanceReed)) ap.request_open();
    ap.tick();
    vTaskDelay(pdMS_TO_TICKS(200));
  }
}

}  // namespace

extern "C" void app_main() {
  const agv::HardwareProfile& profile = agv::default_profile();
  ESP_LOGI(TAG, "ESP32 carte V5.0.1 : client Wi-Fi, profil=%s", profile.name);

  esp_err_t err = nvs_flash_init();
  if (err == ESP_ERR_NVS_NO_FREE_PAGES || err == ESP_ERR_NVS_NEW_VERSION_FOUND) {
    nvs_flash_erase();
    nvs_flash_init();
  }

  g_link_uart.begin(UART_NUM_1, agv::board::kLinkTx, agv::board::kLinkRx,
                    static_cast<int>(profile.link.baud));

  static agv::GatewayApp gateway(profile, g_clock, g_publisher, g_link_port);
  g_gateway = &gateway;
  gateway.begin();

  // La liaison série démarre AVANT le Wi-Fi : le heartbeat vers l'ATmega ne
  // doit pas attendre l'association au réseau d'entreprise, sinon l'AGV reste
  // en repli de sécurité tant que le service informatique n'a pas fini.
  xTaskCreatePinnedToCore(link_task, "link", 6144, nullptr, 6, nullptr, 1);

  start_wifi(profile);
  start_mqtt(profile);

  xTaskCreatePinnedToCore(maintenance_task, "maint", 8192, nullptr, 3, nullptr, 0);

  // Surveillance du niveau reçu : sous le seuil du profil, la couverture n'est
  // plus tenable en mouvement et il faut le savoir avant de perdre des appels.
  for (;;) {
    if (g_wifi_up) {
      const int16_t rssi = wifi_rssi();
      if (rssi != 0 && rssi < profile.wifi.rssi_warn_dbm) {
        ESP_LOGW(TAG, "niveau Wi-Fi faible : %d dBm (seuil %d)", rssi,
                 profile.wifi.rssi_warn_dbm);
      }
    }
    vTaskDelay(pdMS_TO_TICKS(5000));
  }
}

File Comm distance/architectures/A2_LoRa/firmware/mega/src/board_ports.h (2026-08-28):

// Câblage de l'ATmega2560 sur les SUB-D 25 : TABLE RELEVÉE.
//
// Source : relevé de câblage fourni par le client (nappe 25 fils + connecteurs
// IDC SUB-D 25, cosses serties côté AGV sur CN61 à CN64).
// Table complète et lisible : docs/subd25_atmega.md.
//
// Les numéros de broches sont ceux de la carte Arduino MEGA 2560 ; la
// correspondance vers les ports AVR est celle du variant `mega`, rappelée en
// commentaire sur chaque ligne pour que la table reste vérifiable.
//
// TROIS CONSTATS QUI CONDITIONNENT LE DRIVER :
//
//  1. Les 43 signaux occupent ONZE ports, par bits épars. Aucun champ (adresse,
//     vitesse) n'est aligné sur un port : la pose se fait par masques.
//
//  2. PORTA, PORTB et PORTG sont MIXTES (sorties X et entrées Y sur le même
//     port). Toute écriture de DDR ou de PORT doit être masquée : un
//     `DDRA = 0xFF` mettrait D23/Y21 en sortie contre l'automate.
//
//  3. Les 10 bits d'adresse sont sur PORTA, PORTC, PORTG et PORTL : quatre
//     écritures, ~0,25 µs à 16 MHz. Largement sous le `t_setup` attendu.
#pragma once

#include <avr/io.h>

#include "bus/avr_port_bus.h"

namespace agv::board {

// Index des ports dans AvrBusMap::ports.
enum PortIndex : uint8_t {
  kPortA = 0, kPortB, kPortC, kPortD, kPortE,
  kPortF, kPortG, kPortH, kPortJ, kPortK, kPortL,
  kPortCount,
};

inline AvrBusMap bus_map() {
  AvrBusMap m{};
  m.port_count = kPortCount;
  m.ports[kPortA] = {&PORTA, &DDRA, &PINA};
  m.ports[kPortB] = {&PORTB, &DDRB, &PINB};
  m.ports[kPortC] = {&PORTC, &DDRC, &PINC};
  m.ports[kPortD] = {&PORTD, &DDRD, &PIND};
  m.ports[kPortE] = {&PORTE, &DDRE, &PINE};
  m.ports[kPortF] = {&PORTF, &DDRF, &PINF};
  m.ports[kPortG] = {&PORTG, &DDRG, &PING};
  m.ports[kPortH] = {&PORTH, &DDRH, &PINH};
  m.ports[kPortJ] = {&PORTJ, &DDRJ, &PINJ};
  m.ports[kPortK] = {&PORTK, &DDRK, &PINK};
  m.ports[kPortL] = {&PORTL, &DDRL, &PINL};

  // --- SORTIES X (SUB-D femelle) : index = position dans profiles/pinmap.x ---
  //                            broche MEGA    SUB-D   AGV     rôle
  m.x[0]  = {kPortL, 6};  // X82  D43         pin 10  CN63 B5  standby release (départ)
  m.x[1]  = {kPortA, 3};  // X83  D25         pin 23  CN63 A5  standby stop
  m.x[2]  = {kPortA, 0};  // X84  D22         pin 11  CN63 B6  changement d'aiguillage
  m.x[3]  = {kPortB, 2};  // X85  D51         pin 24  CN63 A6  changement de sens
  m.x[4]  = {kPortC, 7};  // X86  D30         pin 12  CN63 B7  vitesse bit 1
  m.x[5]  = {kPortL, 1};  // X87  D48         pin 25  CN63 A7  vitesse bit 2
  m.x[6]  = {kPortC, 6};  // X90  D31         pin 5   CN61 B3  vitesse x4
  m.x[7]  = {kPortL, 3};  // X91  D46         pin 18  CN61 A3  vitesse x8
  m.x[8]  = {kPortA, 4};  // X92  D26         pin 4   CN61 B4  instruction data input switch
  m.x[9]  = {kPortL, 2};  // X93  D47         pin 17  CN61 A3  write input data switch
  m.x[10] = {kPortC, 4};  // X94  D33         pin 3   CN61 B5  type de donnée (station/marqueur)
  m.x[11] = {kPortB, 3};  // X95  D50         pin 16  CN61 A5  frein externe
  m.x[12] = {kPortG, 2};  // X96  D39         pin 2   CN61 B6  destination x1
  m.x[13] = {kPortL, 0};  // X97  D49         pin 15  CN61 A6  destination x2
  m.x[14] = {kPortG, 0};  // XA0  D41         pin 6   CN62 B6  destination x4
  m.x[15] = {kPortL, 5};  // XA1  D44         pin 19  CN62 A6  destination x8
  m.x[16] = {kPortC, 2};  // XA2  D35         pin 7   CN62 B7  destination x16
  m.x[17] = {kPortL, 4};  // XA3  D45         pin 20  CN62 A7  destination x32
  m.x[18] = {kPortA, 6};  // XA4  D28         pin 8   CN62 B8  destination x64
  m.x[19] = {kPortC, 0};  // XA5  D37         pin 21  CN62 A8  destination x128
  m.x[20] = {kPortA, 7};  // XA6  D29         pin 9   CN62 B9  destination x256
  m.x[21] = {kPortA, 2};  // XA7  D24         pin 22  CN62 A9  destination x512
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

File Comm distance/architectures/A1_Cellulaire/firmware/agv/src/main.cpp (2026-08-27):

// Firmware embarqué sur l'AGV : cœur du projet.
//
// Répartition FreeRTOS imposée par le §4.4 :
//   cœur 1 : tâche BUS. Séquenceur trois phases et pose du bus MEIDEN. La
//            section adresse+vitesse+strobe s'exécute en section critique.
//   cœur 0 : tâche LIAISON. Pile radio/modem, télémétrie, serveur de
//            maintenance. Rien de ce qui vit ici ne doit pouvoir retarder la
//            pose du bus.
//
// ⚠ CE FIRMWARE N'EST PAS UN ORGANE DE SÉCURITÉ (brief §3.1). L'arrêt
// d'urgence, les bumpers et le scrutateur laser restent dans une chaîne
// indépendante conforme à l'ISO 3691-4. Aucune ligne de ce fichier ne doit
// prétendre assurer une fonction de sécurité.
#include <freertos/FreeRTOS.h>
#include <freertos/semphr.h>
#include <freertos/task.h>

#include <esp_log.h>

#include "app/agv_app.h"
#include "app/course_queue.h"
#include "app/sequencer.h"
#include "board_pins.h"
#include "bus/mcp23017_bus.h"
#include "bus/mega_uart_bus.h"
#include "bus/shift_bus.h"
#include "config/hardware_profile.h"
#include "maintenance_ap.h"
#include "platform/esp32/esp_ports.h"
#include "platform/esp32/nvs_store.h"
#include "transport/mqtt_lte_transport.h"
#include "transport/sms_transport.h"

namespace {

const char* TAG = "agv";

agv::esp32::EspClock g_clock;
agv::esp32::EspUart g_modem_uart;
agv::esp32::EspModemPower g_modem_power(agv::board::kModemPwrkey, agv::board::kWatchdogDone);
agv::esp32::EspI2c g_i2c;
agv::esp32::EspSpi g_spi;
agv::esp32::EspGpio g_gpio;
agv::esp32::NvsStore g_nvs;
agv::RamStore g_fallback_store;

// Signalisation locale : LED FAULT et LED liaison.
class BoardIndicators final : public agv::IIndicators {
 public:
  void begin() {
    g_gpio.configure_output(agv::board::kLedFault);
    g_gpio.configure_output(agv::board::kLedLink);
  }
  void set_fault(bool on) override { g_gpio.set(agv::board::kLedFault, on); }
  void set_link(bool on) override { g_gpio.set(agv::board::kLedLink, on); }
};

BoardIndicators g_indicators;

// Sélection de la variante d'interface bus (§12.10) : NON TRANCHÉE. Le choix
// vient du profil, pas d'un #ifdef enfoui dans le code métier.
agv::IBusDriver* make_bus_driver(const agv::HardwareProfile& profile) {
  static agv::esp32::EspUart mega_uart;
  switch (profile.bus.variant) {
    case agv::DriverVariant::Mcp23017: {
      static agv::Mcp23017Bus driver(profile, g_i2c, g_clock);
      return &driver;
    }
    case agv::DriverVariant::Shift595: {
      static agv::ShiftPins pins{agv::board::kShiftRclk, agv::board::kShiftPl,
                                 agv::board::kShiftOe};
      static agv::ShiftBus driver(profile, g_spi, g_gpio, g_clock, pins);
      return &driver;
    }
    case agv::DriverVariant::MegaUart: {
      mega_uart.begin(UART_NUM_2, agv::board::kMegaTx, agv::board::kMegaRx, 500000);
      static agv::MegaUartBus driver(profile, mega_uart, g_clock);
      return &driver;
    }
    case agv::DriverVariant::Sim:
    default:
      // Le profil « sim » n'a pas de sens sur cible : c'est une erreur de
      // configuration, signalée plutôt que contournée silencieusement.
      ESP_LOGE(TAG, "profil 'sim' flashé sur cible réelle : vérifier profiles/*.yaml");
      return nullptr;
  }
}

struct Runtime {
  const agv::HardwareProfile* profile = nullptr;
  agv::IBusDriver* bus = nullptr;
  agv::CourseQueue* queue = nullptr;
  agv::Sequencer* sequencer = nullptr;
  agv::ITransport* transport = nullptr;
  agv::AgvApp* app = nullptr;
  SemaphoreHandle_t lock = nullptr;
};

Runtime g_rt;

// --- Tâche BUS (cœur 1) -----------------------------------------------------
void bus_task(void*) {
  const TickType_t period = pdMS_TO_TICKS(2);  // 500 Hz : très au-dessus des
                                               // constantes de temps du bus
  TickType_t last = xTaskGetTickCount();
  for (;;) {
    xSemaphoreTake(g_rt.lock, portMAX_DELAY);
    g_rt.sequencer->tick();
    xSemaphoreGive(g_rt.lock);
    vTaskDelayUntil(&last, period);
  }
}

// --- Tâche LIAISON (cœur 0) -------------------------------------------------
void link_task(void*) {
  for (;;) {
    xSemaphoreTake(g_rt.lock, portMAX_DELAY);
    g_rt.app->tick();
    xSemaphoreGive(g_rt.lock);
    vTaskDelay(pdMS_TO_TICKS(5));
  }
}

// --- Tâche MAINTENANCE (cœur 0) ---------------------------------------------
// Wi-Fi désactivé par défaut, ouvert 10 min sur contact ILS (§9.4).
void maintenance_task(void*) {
  agv::maintenance::AccessPoint ap(*g_rt.profile, g_clock);
  ap.set_dump_source([](char* out, size_t cap) { return g_rt.app->render_agvdump(out, cap); });
  g_gpio.configure_input(agv::board::kMaintenanceReed, true);
  for (;;) {
    // Contact ILS actif bas (aimant présent).
    if (!g_gpio.get(agv::board::kMaintenanceReed)) ap.request_open();
    ap.tick();
    vTaskDelay(pdMS_TO_TICKS(200));
  }
}

}  // namespace
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

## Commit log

2026-08-13 feat: logiciel complet de la carte de communication AGV MEIDEN
    Remplacement de la carte AIO AGV Control V5.0.1 (§14 étapes 1 à 8).
    - sim/ : simulateur d'automate MEIDEN en temps virtuel, écrit en premier
    - common/ : trame, CRC-16, AES-128-CTR, idempotence, IBusDriver, ITransport
    - séquenceur trois phases en machine à états explicite, compteurs agvdump
    - file de 5 courses persistée en NVS avec politique de validité
    - trois variantes d'interface bus (MCP23017, 74HC595+165, ATmega2560)
    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
    [IT1.kicad_pcb, IT1.kicad_sch]
2026-08-14 refactor: un dossier autonome par architecture sous CarteComm/
    Chaque architecture devient un projet complet et zippable indépendamment.
    - CarteComm/SMS_EnOcean/ : projet entier (boutons EnOcean sans pile au poste
    fixe, liaison cellulaire vers l'AGV). Les deux main.cpp passent sur
    MqttLteTransport, avec SmsTransport en variante de comparaison.
    - CarteComm/LoRa/ : sources LoRa extraites (transport half-duplex, budget
    ERC 70-03, pilote SX1276, bouton sur pile, 10 tests, note de latence).
    LoraConfig est sorti de HardwareProfile : le cœur partagé ne transporte plus
    de paramètre radio, ce qui rend la greffe indolore.
    - CarteComm/README.md : index des architectures et rappel que le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
    [IT1.kicad_pcb, IT1.kicad_sch]
2026-08-14 feat(wifi): architecture Wi-Fi — carte V5.0.1 conservée, deux firmwares réécrits
    Suit CarteComm/Wifi/Planification_Architecture_WiFi_AGV.md. Le matériel ne
    change pas ; le firmware d'origine n'étant disponible ni en sources ni en
    binaire garanti, les deux programmes sont réécrits.
    Répartition des rôles, décision structurante :
    - ATmega2560 : séquenceur trois phases, file de 5 courses, décodage position,
    pose des 22 lignes en une seule section critique (PORTx = valeur).
    - ESP32 : client Wi-Fi STA (plus de point d'accès permanent), client MQTT
    (state retained, cmd, ack, LWT), heartbeat, AP de maintenance, /agvdump.
    Il ne touche jamais au bus MEIDEN.
    Repli de sécurité n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
    [AIO_AGV_Control_V5.0.1.kicad_pcb, AIO_AGV_Control_V5.0.1.kicad_sch]
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2026-08-16 fix(wifi): le rail 6 V est sur l'étage de sortie, pas sur les entrées
    Correction d'une erreur d'analyse : le LM7806 alimente l'étage de SORTIE de la
    carte d'origine. Les entrées de l'automate sont donc dimensionnées pour du 6 V,
    alors que l'ATmega ne sort que 5 V. Les entrées Y ne sont pas concernées.
    Conséquence, et vraie découverte : si les entrées de l'automate sont tirées à
    6 V et que la carte d'origine se contentait de tirer à la masse, une sortie 5 V
    poussée contre ce tirage fait remonter du courant dans la diode de protection de
    la broche du microcontrôleur — défaut sournois, qui « marche » au banc et
    dégrade la broche en service.
    Ajout d'un mode collecteur ouve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
    [avr_port_bus.cpp]
2026-08-17 fix(wifi): le L7806CV est l'alimentation de l'ATmega, pas un étage de signal
    Analyse du PCB : le L7806CV abaisse le 24 V arrivant sur CN64 A6/B6 (RP24B) à
    6 V pour alimenter l'ATmega2560. Ce n'est ni un étage de sortie, ni un niveau de
    signal — les deux interprétations précédentes étaient fausses.
    Conséquences :
    - les niveaux du bus redeviennent entièrement inconnus. L'amplitude des lignes Y
    (W1b) repasse BLOQUANT : elles arrivent directement sur des broches d'ATmega,
    et au-delà de V_CC + 0,5 V l'entrée est détruite ;
    - question nouvelle (W1e) : 6,0 V est la valeur MAXIMALE ABSOLUE du datasheet de
    l'ATmega2560, et la plage recommandée s'arrête à 5,5 V. Un L7806 sort j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
    [avr_port_bus.cpp]
2026-08-17 docs(wifi): runbook de déploiement complet
    DEPLOY.md : procédure opérationnelle en 11 phases, des mesures préalables au
    procès-verbal de recette.
    Trois points mis en tête parce qu'ils sont irréversibles ou bloquants :
    - flasher détruit le firmware d'origine si la sauvegarde échoue — la phase 2
    donne les commandes esptool/avrdude, et impose une décision écrite du client
    si les bits de protection interdisent la relecture ;
    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
    [AIO_AGV_Control_V5.0.1.kicad_pcb, AIO_AGV_Control_V5.0.1.kicad_sch]
2026-08-18 KiCad AGV Control 5.0.1
    [AIO_AGV_Control_V5.0.1.kicad_pcb, AIO_AGV_Control_V5.0.1.kicad_sch]
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2026-08-18 docs: un runbook de déploiement par architecture
    Chaque dossier porte désormais son DEPLOY.md. Les procédures n'ont presque rien
    en commun : les recopier aurait produit trois documents faux.
    SMS_EnOcean/DEPLOY.md — 10 phases. Quatre décisions en tête : déployer
    MQTT/LTE-M et jamais le SMS en liaison principale (les environnements SMS
    existent pour la comparaison chiffrée), faire acter le coût récurrent
    (~1 500 €/an en SMS contre ~100 € en LTE-M), la couverture cellulaire
    éliminatoire — un point sous −110 dBm disqualifie l'architecture, et le choix de
    variante d'interface bus qui conditionne le routage du PCB. Inclut le
    provisionnement de la clé AES applicative (pas de T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
2026-08-19 docs: nomenclature chiffrée pour chaque architecture
    Un BOM.md par dossier, construit sur les nomenclatures des documents de
    référence (Archi_1 §6, Archi_2 §6, Archi_3 §6, planification §11) et complété de
    ce que le code impose réellement.
    Chaque nomenclature couvre : carte AGV, poste fixe, boutons, outillage,
    récurrent, coût sur 10 ans, coût par station supplémentaire, délais et risques
    d'approvisionnement, et ce que le chiffrage ne couvre pas.
    Ce que l'exercice fait apparaître :
    - le Wi-Fi n'est PAS le moins cher malgré sa carte AGV à 0 € — le poste UniPi à
    461 € pèse plus que les 98 € d'une carte LoRa neuve. Son avantage est ailleurs :
    aucun PCB à fabri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
2026-08-19 Update routage PCB
    [AIO_AGV_Control_V5.0.1.kicad_pcb, AIO_AGV_Control_V5.0.1.kicad_sch]
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2026-08-20 feat(wifi): nomenclature de la carte AGV extraite du projet KiCad
    La carte est désormais chiffrée sur sa vraie nomenclature — 57 composants
    placés au PCB — et non sur une estimation d'étude. Deux découvertes en
    découlent, dont une correction de firmware.
    1. L'étage de sortie est à MOSFET, et le firmware était configuré à l'envers.
    Les 22 voies X passent par 23 IRF520 attaqués par des résistances de grille
    de 1 kΩ : le collecteur ouvert est réalisé PAR LE MATÉRIEL. Le
    microcontrôleur pilote donc une grille et doit être en sortie poussée.
    `bus.x_open_drain` passe à false. Le réglage précédent aurait laissé la
    grille FLOTTANTE à l'état actif — un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
2026-08-20 feat(wifi): poste fixe sur Unipi Gate G100 au lieu d'un automate à E/S
    Le service du poste n'utilise qu'un port série et de l'Ethernet : le récepteur
    EnOcean d'un côté, le broker MQTT de l'autre. Les boutons étant EnOcean, aucune
    entrée TOR n'est employée — io_backend.py n'est même pas appelé par __main__.py.
    Payer un automate à entrées/sorties revenait à financer du matériel inutilisé.
    L'Unipi Gate G100 (~200 € contre 375 €) couvre exactement le besoin : Debian,
    16 Go eMMC, 2 ports Ethernet, USB 3.0, RS485, alimentation 6-36 VDC, rail DIN.
    Trois gains au-delà des 175 € :
    - le point ouvert §12.9 DISPARAÎT. Le Gate est livré sous Debian, donc le
    service Python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
2026-08-20 docs(bom): analyse critique de chaque architecture, nomenclatures adaptées
    Revue composant par composant des trois nomenclatures. Deux corrections
    effectives, le reste documenté comme décisions à prendre.
    LoRa — le TPS62740 du bouton sur pile est retiré. La pile Li-SOCl2 délivre
    3,6 V, que le STM32L071 (1,65-3,6 V) et le RFM95W (1,8-3,7 V) acceptent
    directement : le convertisseur ajoutait un composant, un courant de repos et un
    mode de panne pour rien. Le vrai besoin est ailleurs — l'impédance interne
    d'une cellule Li-SOCl2 est élevée et l'émission tire ~120 mA, donc la tension
    s'effondre sans réservoir et le microcontrôleur redémarre. Remplacé par
    220 uF + 10 uF, plus une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
2026-08-20 feat(sms): le poste cellulaire peut descendre en gamme UniPi si Ethernet
    Suite de l'analyse critique : l'E413 n'était imposé que par son modem intégré.
    Or l'AGV et le poste portaient chacun une SIM, et le poste n'a aucune raison de
    passer par le réseau opérateur dès qu'une prise réseau est à portée. Le besoin
    qui justifiait le modèle disparaît, et la gamme Gate redevient éligible.
    Le poste fixe se scinde donc en trois options au lieu de deux :
    A - ESP32 sur mesure, 177 EUR TTC, la moins chère dans tous les cas
    B - Unipi Gate G100 si une prise réseau existe sur place, 545 EUR HT au total
    C - UniPi E413 LTE seulement sinon, 698 EUR HT
    183 EUR TTC d'écart de matériel en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
2026-08-21 docs(lora): demande de prix pour la variante A3, symétrique de l'A1
    email_commande.md devient email_commande_A1.md, et l'A3 hybride reçoit son
    courrier. Trois listes au lieu de deux : carte embarquée, poste fixe, boutons.
    La carte et le poste partagent la même base électronique - ESP32, RFM95W, TSR,
    LDO, pigtail et antenne LoRa passent donc à 2 dans la première liste, ce que le
    document dit explicitement pour éviter qu'on croie à une erreur de saisie. Les
    lignes groupées de la BOM (pigtail + antenne, TSR + LDO) sont éclatées, un
    fournisseur ne pouvant pas chiffrer une ligne double.
    Le courrier insiste sur un point : la version EU 868 MHz du PTM 210 est
    impérative, les déclina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
2026-08-21 feat: réutiliser la carte V5.0.1 pour le LoRa, et corriger la liaison inter-MCU
    La lecture du projet KiCad valide la réutilisation et corrige un bug réel.
    L'ESP32-DEVKITC de la V5.0.1 n'utilise que 4 de ses 38 broches : deux
    d'alimentation et deux vers le Mega2560 Pro. Les 34 autres ne sont connectées à
    rien. Il y a donc la place d'y greffer un RFM95W en SPI - IO18, IO19, IO23, IO5,
    DIO0 et RESET sont toutes libres. La répartition des rôles ne bouge pas : le
    MEGA porte la mission et les 43 lignes, l'ESP32 porte la radio. Seule la radio
    change entre l'architecture Wi-Fi et l'architecture LoRa.
    La carte AGV passe de 98,20 à 27,00 EUR HT, et surtout le chemin critique
    matériel dispar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
    [main.cpp]
2026-08-24 test(lora): essais radio d'émission et de réception, côté ESP32 et côté Linux
    Deux sous-dossiers dans LoRa/test/, chacun avec un essai d'émission et un de
    réception, donc quatre combinaisons possibles. Les deux croisées - ESP32 vers
    Linux et Linux vers ESP32 - sont les seules qui prouvent quelque chose : une
    implémentation confrontée à elle-même ne démontre que sa propre cohérence.
    Le point de conception est là. Une radio qui porte et des trames qui divergent
    d'un bit donnent un banc parfait et une panne en atelier, alors les deux côtés
    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
    [AIO_AGV_Control_V5.0.1.kicad_pcb, AIO_AGV_Control_V5.0.1.kicad_sch]
2026-08-25 feat(bom): resserrer les nomenclatures sur les composants déterminants
    Les accessoires arbitrables selon le budget - antennes, boîtiers, coffrets,
    enveloppes murales, câbles, plaques gravées - sortent de l'affichage et des
    sous-totaux. Trente-six lignes qui se substituent librement d'un fournisseur à
    l'autre et n'engagent aucun choix de conception : elles allongeaient la lecture
    sans rien apporter à la décision.
    Elles restent définies dans generer_bom.py, marquées core=False. Rien n'est
    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
    [AIO_AGV_Control_V6.0.kicad_pcb, AIO_AGV_Control_V6.0.kicad_sch]
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2026-08-25 refactor: un dossier par architecture, et la V6.0 rendue au LoRa
    L'organisation suivait le mode de communication ; elle suit désormais
    l'architecture. SMS_EnOcean devient A1_Cellulaire, Wifi devient A4_Wifi, LoRa
    devient A2_LoRa, et A3_Hybride est créé.
    A2 et A3 n'étaient qu'un dossier de sources non autonome. Ils reçoivent le coeur
    métier de A4 - c'est lui qui porte le duo MEGA + ESP32 de la carte V6.0, pas le
    firmware mono-ESP32 de A1 - plus le transport LoRa déjà écrit, et A3 y ajoute le
    décodage ESP3 et le poste fixe. Les quatre dossiers compilent et testent seuls :
    112, 119, 130 et 109 tests, tous verts.
    Côté matériel, AIO_AGV_Control_V6.0 quitte A4 pour A2 et A3. Le rele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
    [AIO_AGV_Control_V5.0.1.kicad_pcb, AIO_AGV_Control_V5.0.1.kicad_sch, AIO_AGV_Control_V6.0.kicad_pcb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]
2026-08-25 refactor: permuter A2 et A3, l'hybride ayant précédé le LoRa pur
    L'hybride EnOcean + LoRa devient A2, le LoRa pur devient A3. Les dossiers
    suivent - A3_Hybride devient A2_Hybride, A2_LoRa devient A3_LoRa - ainsi que
    les documents de référence Archi_2 et Archi_3.
    Chaque dossier ne garde désormais que sa propre spécification. La duplication
    qui avait créé A3 avait laissé les deux documents dans les deux dossiers, ce qui
    donnait un Archi_3 dans le dossier A2 : la copie étrangère est retirée, et les
    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
    [AIO_AGV_Control_V6.0.kicad_pcb, AIO_AGV_Control_V6.0.kicad_sch]
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2026-08-25 feat(lora): remplacer la passerelle MQTT par une passerelle LoRa dans A2 et A3
    Vous aviez raison de relever l'incohérence : ces deux architectures n'ont ni
    broker, ni réseau d'entreprise, et leur firmware ESP32 portait pourtant un
    GatewayApp qui publiait sur des topics et dépendait d'IMqttPublisher. Je l'avais
    laissé en dette plutôt que de l'écrire.
    LoraGatewayApp le remplace. Il rend exactement le même service côté ATmega -
    mêmes trames de liaison, même heartbeat, même repli de sécurité - et change
    seulement la source des ordres : trames applicatives de 9 octets sur ITransport,
    accusé renvoyé par la même voie, idempotence (node_id, seq) en table locale.
    Le budget de rappo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
    [AIO_AGV_Control_V6.0.kicad_pcb, AIO_AGV_Control_V6.0.kicad_sch]
2026-08-26 feat(banc): banc d'essai des boutons EnOcean pour UniPi E413
    Service web qui enregistre les PTM 210, les détecte à l'appui ou par saisie de
    l'identifiant, et ouvre une fenêtre verte à chaque pression avec le nom, le
    code, l'heure et le niveau reçu.
    Deux règles font la différence entre un banc utilisable et un banc qui ment. Un
    PTM 210 émet TROIS sous-télégrammes par appui, et émet aussi au relâchement :
    sans traitement, une pression afficherait six fenêtres. Le banc déduplique sur
    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
    [AIO_AGV_Control_V6.0.kicad_pcb, AIO_AGV_Control_V6.0.kicad_sch]
2026-08-26 refactor: organiser le dépôt par nature d'objet
    L'arborescence suivait l'histoire du projet plutôt qu'une logique. Elle suit
    maintenant la nature de ce qu'elle contient :
    architectures/ les 4 solutions complètes
    bancs/ les essais matériels
    materiel/ les projets KiCad
    docs/ brief et comparatif
    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
    [AIO_AGV_Control_V5.0.1.kicad_pcb, AIO_AGV_Control_V5.0.1.kicad_sch, AIO_AGV_Control_V6.0.kicad_pcb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]
2026-08-26 fix(banc): fenêtre d'ajout invisible et identifiant capté non repris
    Deux défauts relevés à l'essai sur la UniPi, avec la même conséquence : le mode
    détection ne servait à rien.
    La fenêtre d'ajout restait affichée en permanence. .voile déclarait
    display: flex, et la moindre règle d'auteur déclarant display bat l'attribut
    hidden du HTML - qui n'est qu'un display: none de la feuille par défaut du
    navigateur. La boîte était donc visible depuis le chargement de la page, sans
    que rien ne l'ait ouverte. Une règle [hidden] { display: none !important }
    rétablit l'attribut pour tout le document, y compris les éléments qui
    gagneraient une règle display plus tard.
    L'écoute d'ap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
2026-08-26 fix(banc): la fenêtre d'ajout ne se fermait toujours pas
    Mon correctif précédent était juste mais ne pouvait pas suffire. Tant que la
    visibilité de la fenêtre reposait sur l'attribut hidden, elle restait à la merci
    de n'importe quelle règle de feuille déclarant display - et d'une feuille
    périmée servie par le cache du navigateur, contre laquelle aucune correction CSS
    ne peut rien.
    La visibilité est donc portée par un style EN LIGNE, posé par afficherModale().
    Un style en ligne l'emporte sur toute règle de feuille sans !important, y
    compris sur une version ancienne du fichier. La feuille déclare désormais
    display: none par défaut pour la voile, et l'état initial est posé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
2026-08-27 refactor: dépôt unique à la racine AGV_MEIDEN, deux chantiers frères
    Le dépôt vivait dans ce qui est devenu « Comm distance/ » ; un second chantier
    (Timer, planning journalier) démarre à côté. Décision : un seul dépôt à la
    racine, englobant les deux.
    Réalisé proprement : le .git est REMONTÉ à la racine plutôt que réinitialisé.
    Git enregistre un renommage de tout le contenu vers Comm distance/ - 456
    renommages, aucune perte d'historique, git log --follow traverse. L'alternative
    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
    [AIO_AGV_Control_V5.0.1.kicad_pcb, AIO_AGV_Control_V5.0.1.kicad_sch, AIO_AGV_Control_V6.0.kicad_pcb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]
2026-08-27 feat(timer): moteur du planning journalier, 18 tests
    Fondation du chantier Timer (spec dans Timer/Spec Planning Journalier.md) : le
    moteur d'ordonnancement du §4, en C++ pur, horloge injectée, zéro dépendance
    ESP-IDF - la même approche que le codec LoRa, testable sur poste en
    millisecondes.
    Couvert : occurrences par masque de jours avec bornes de validité et
    exceptions ; validation quotidienne du §3.2 (rien ne part sans autorisation du
    jour, celle d'hier ne vaut pas, traçabilité valide_par/valide_le) ; fenêtre de
    grâce de 5 minutes avec saut journalisé au-delà et jamais de rejeu de la
    journée au redémarrage ; idempotence par (id, date locale), qui règle au
    passage le 02:30 d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
2026-08-27 fix(timer): drapeaux invisibles et pastilles jamais rendues ; gestion des postes
    Deux défauts de rendu, tous deux réels, tous deux à moi.
    Les drapeaux ne s'affichaient pas parce que .fanion déclarait color:#fff ET
    background:currentColor. currentColor se résout contre la couleur de l'élément
    lui-même, pas celle du parent : fanion blanc-sur-blanc, il ne restait que le
    mât de 2 px. La couleur d'état vit maintenant sur .drapeau seul, le blanc du
    texte sur le span, et un commentaire CSS interdit d'y reposer color. Les mâts
    descendent désormais jusqu'à l'axe des heures : le drapeau est planté.
    Les pastilles de postes n'apparaissaient jamais : rendrePostes() n'était appelé
    qu'au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
2026-08-27 fix(timer): la frise mentait sur l'occupation de l'AGV
    Vous aviez raison, et le chiffre est net : l'étiquette d'un départ mesurait 92
    pixels sur une frise de 1030, soit 2,1 heures d'immobilisation apparente. Un
    trajet dure au plus 5 minutes à vitesse lente : 0,35 % de la journée, 3,6
    pixels. La frise affichait donc une occupation vingt-cinq fois trop longue.
    La cause était de confondre deux objets. La correction les sépare : un bloc
    d'occupation à l'échelle RÉELLE, posé sur l'axe des heures, et une étiquette
    détachée au-dessus, reliée par une amorce d'un pixel, qui n'engage aucune
    durée. On lit désormais l'immobilisation sur l'axe et le libellé au-dessus,
    sans les confondre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
2026-08-27 fix(timer): la frise grandit avec la journée au lieu de saturer
    Sa hauteur et ses trois rangées d'étiquettes étaient figées dans la feuille de
    style : au quatrième départ, les libellés n'avaient plus où aller.
    Toute la géométrie verticale passe dans un objet GEO du script - marge haute,
    pas entre rangées, respiration, bandeau des heures - et la hauteur de la frise
    est calculée à partir des rangées réellement occupées, jusqu'à dix, avec un
    plancher à trois pour qu'une journée vide reste lisible. Elle grandit et
    redescend au fil des ajouts.
    Vérifié sur une journée chargée plutôt que sur un cas d'école : onze départs
    répartis sur quatre rangées, aucun chevauchemen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
2026-08-27 feat(timer): rapporter l'arrêt de sécurité, et corriger ma phase 0
    Deux choses, dont une correction de ma part.
    J'avais présenté la sécurité machine comme éliminatoire, sur le scénario d'une
    personne sur le trajet à 06:00 alors que personne n'a rien demandé. C'était
    surestimé : l'AGV porte sa propre chaîne, indépendante de ce logiciel, qui
    coupe la puissance sur obstacle et n'est réarmée que par un appui physique. Le
    risque de heurt est traité par cette chaîne, que le déplacement soit demandé
    par un opérateur ou par une horloge.
    Ce qui change réellement avec le déclenchement autonome n'est pas la blessure
    mais la surprise, et surtout l'indisponibilité : un arrêt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
2026-08-27 docs(timer): recaler DEPLOY.md sur l'analyse V5.0.1
    Vous avez eu raison de demander. J'avais écrit CHEMIN_V5.md et recalé le
    kanban, mais laissé DEPLOY.md sur l'analyse précédente : deux documents du même
    dossier disaient des choses différentes du même sujet. C'est précisément la
    divergence que la règle de tenue documentaire existe pour éviter.
    Six écarts corrigés.
    La phase 0 s'intitulait « ce qui interdit la mise en service » alors que je
    venais d'établir que la sécurité machine n'est pas éliminatoire : seul t_setup
    l'est, et le titre le dit maintenant. Le §0.4 sur l'arrêt de sécurité, ajouté
    au tour précédent, s'était inséré entre 0.1 et 0.2 - remis après 0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
2026-08-27 docs: retirer les tirets cadratins de tout le dépôt
    2318 occurrences sur 360 fichiers : documentation, commentaires de code,
    chaînes affichées et gabarits web. Le client les trouve pénibles à lire.
    Le remplacement est contextuel, pas uniforme : un tiret rendu partout par le
    même signe aurait produit une prose aussi lourde que celle qu'on corrige. Les
    règles retenues sont celles de la ponctuation française usuelle. Deux-points
    quand ce qui suit explique ou annonce. Virgule quand il s'agit d'une liaison,
    notamment après et, mais, donc, dont, notamment, volontairement. Parenthèses
    pour une incise complète, plutôt que deux virgules qui feraient une enfilade
    illisible. Trait d'union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
    [__main__.py, at_engine.cpp, avr_port_bus.cpp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]
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
